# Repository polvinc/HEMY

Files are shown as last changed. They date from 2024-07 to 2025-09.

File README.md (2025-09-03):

# HEMY v2 – Harmonic Equatorial Mount Yourself

<!-- > _"When astronomy meets DIY and open source, accessible tools are born to explore the universe."_  
> — polvinc -->

**HEMY v2** is an open-source equatorial/alt-azimuth telescope mount designed for passionate astrophotographers and visual observers. Built around **harmonic drive technology**, HEMY offers high precision, portability, and affordability — without compromising on performance.

It is the result of a collaborative and iterative development effort to deliver a powerful, open-source alternative to proprietary commercial mounts.

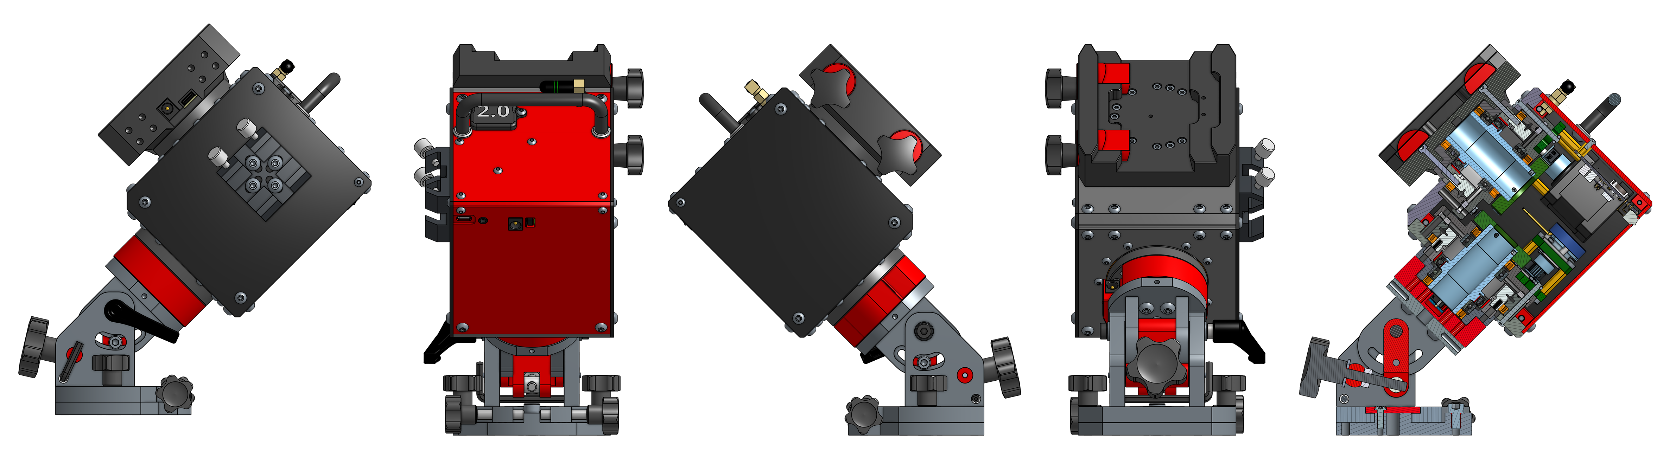
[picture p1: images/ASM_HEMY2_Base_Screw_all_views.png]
HEMY2_all_views


---

## 🚀 Project Description

**HEMY (Harmonic Equatorial Mount Yourself)** is a DIY telescope mount based on industrial-grade **harmonic reducers**, typically used in robotics. These reducers enable compact, backlash-free motion with high torque — ideal for precise astronomical tracking.

The project was created to address key issues in amateur astronomy equipment:
- High prices of commercial mounts
- Lack of openness and flexibility
- Complexity or incompatibility with personal setups

HEMY is:
- 🧰 **Cost-effective** – Total build cost under **800–1000 €**, with machined parts available for less than 400 €
- 🪶 **Portable & lightweight** – Less than 4 kg without base
- 🏗️ **Easy to build** – Designed for makers with basic tools
- 💪 **High-performance** – Accurate tracking (sub-arcsecond RMS), no counterweights needed

⚠️ **Important note about current status** ⚠️

This project is under continuous development. Initial performance tests are promising (13 kg and guiding <1 arcsec) and updates will be published regularly.

---

## ✨ Key Features

| Feature | Description |
|---|---|
| Mount Type | Equatorial / Alt-Az |
| Technology | Harmonic drive + timing belts + NEMA17 motors |
| Payload Capacity | Up to **15 kg**, no counterweights |
| Resolution | ~0.14 arcsec |
| Periodic Error | ~440s cycle, ~±10 arcsec peak-to-peak |
| Controller Compatibility | OnStepX, TeenAstro |
| Connectivity | USB-C, Wi-Fi, Bluetooth, integrated GPS |
| Features | RA axis brake, FRAM-based sensorless homing, 12V passthrough |
| Estimated Cost | ~800–1000 € total |
| Weight | < 4 kg (excluding base) |
| License | **GPL-3.0** |

---

## 🔧 Build Resources

- 🖥️ Full CAD files and STEP for mechanical parts  
- 🔗 [Link to _onshape_ project](https://cad.onshape.com/documents/5bb7abe94ccc1dfccd880b05/w/c4dcfbc560d188dfaca97350/e/5198383ed1b9d7f502f35102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)
- 🛠️ CNC-ready aluminum part kits (not available for now)  
- 📖 Detailed build guide and wiring instructions  
- 🧪 Currently tested and improved through real-world imaging

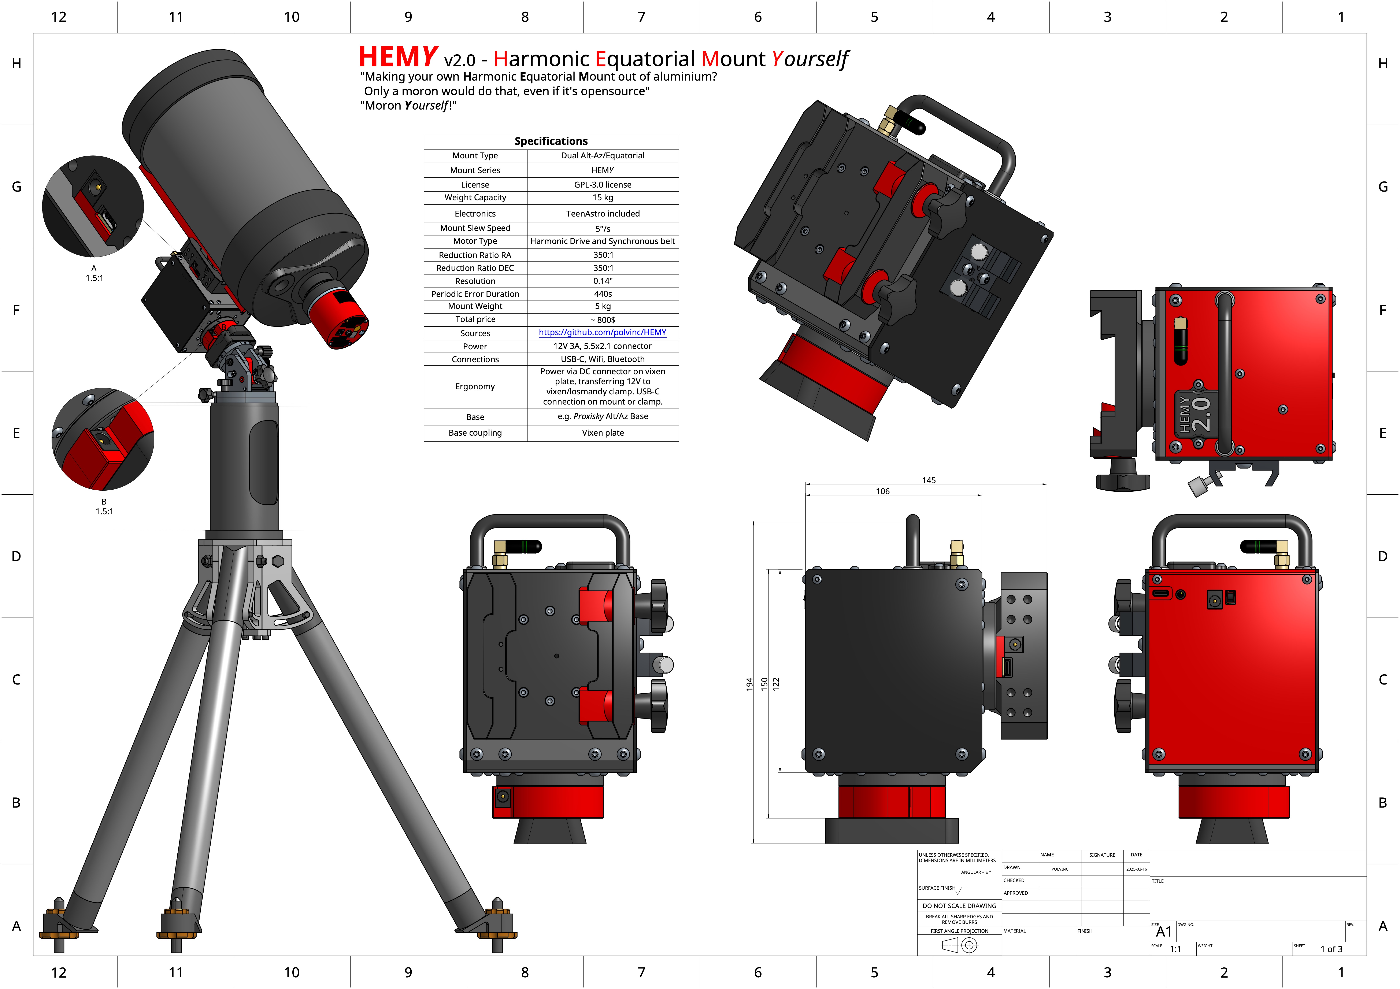
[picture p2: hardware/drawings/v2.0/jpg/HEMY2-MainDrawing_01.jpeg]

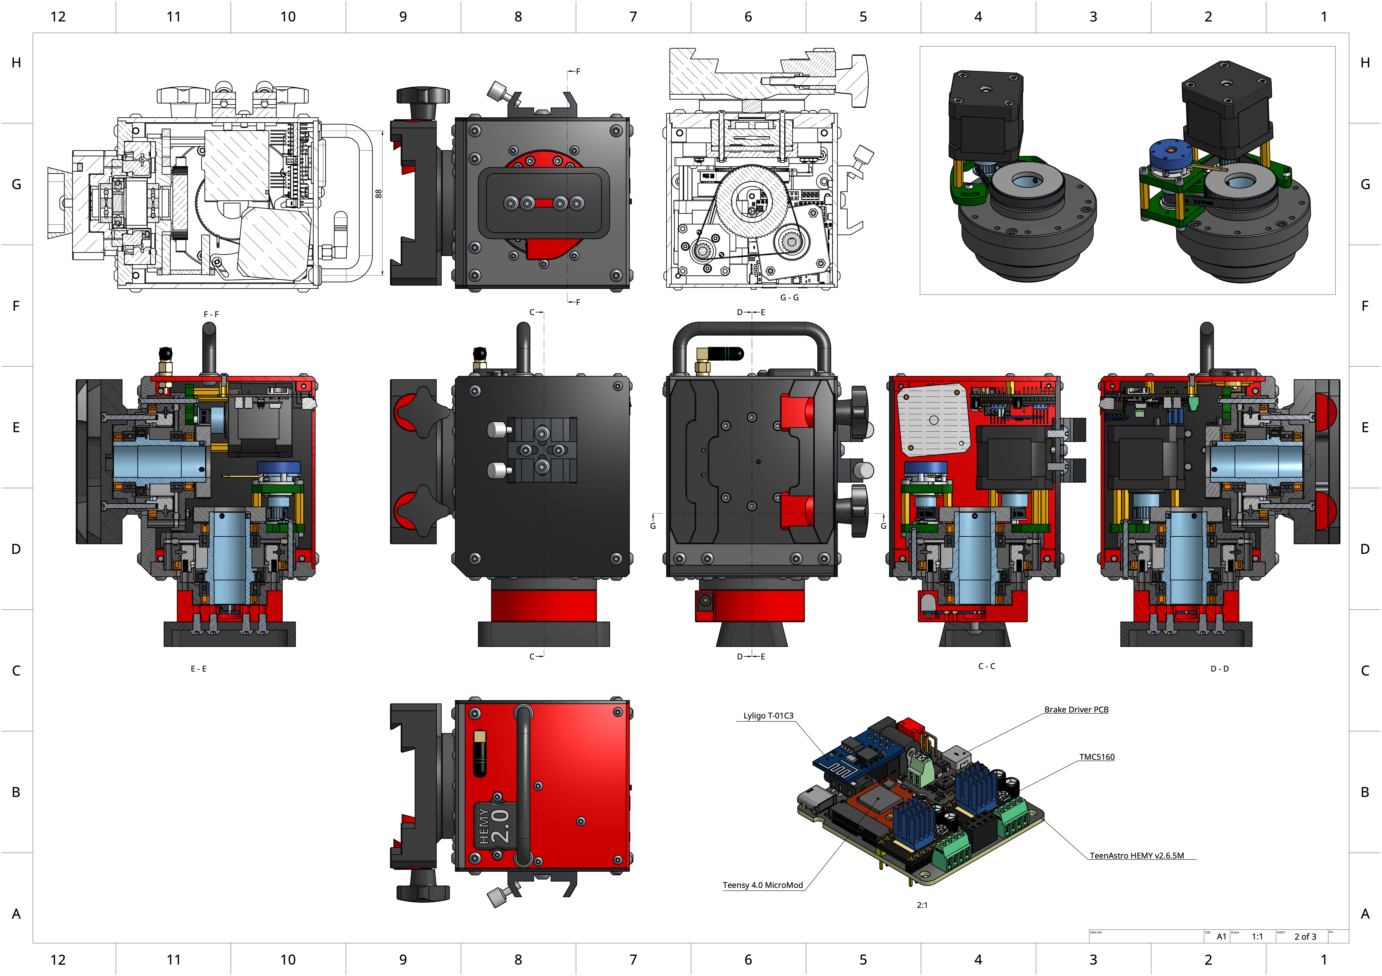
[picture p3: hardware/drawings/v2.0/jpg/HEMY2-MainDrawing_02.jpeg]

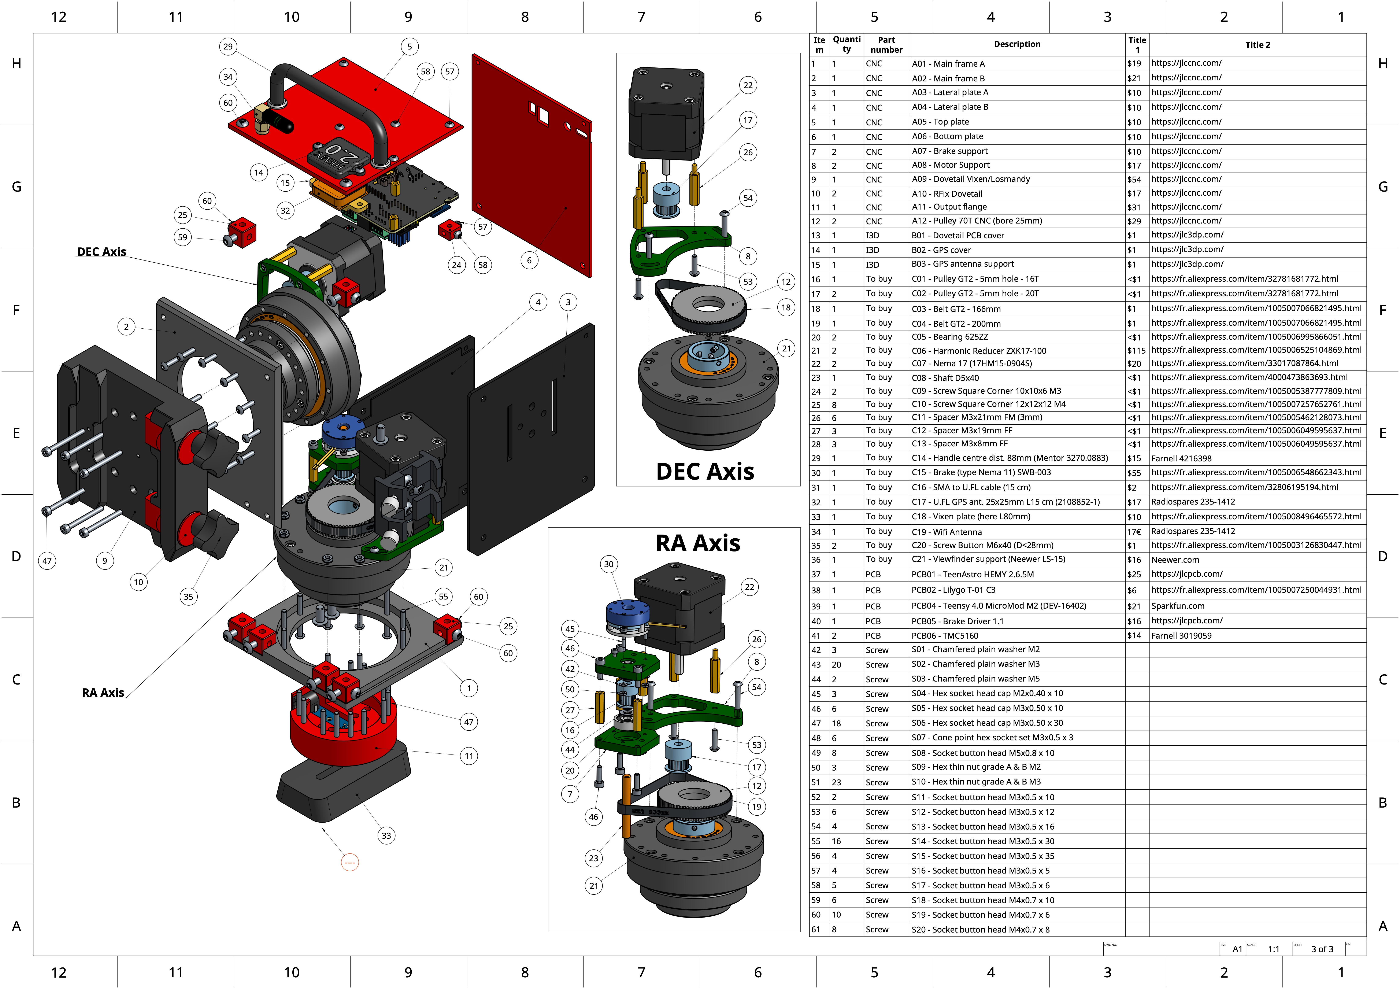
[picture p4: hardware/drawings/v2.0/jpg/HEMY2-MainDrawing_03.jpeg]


---

### Join the HEMY community on Discord ✨

We’ve opened a **Discord server** to bring together users, builders, and contributors around the open-source harmonic mount.

👉 [https://discord.gg/SYYkTSaXZt](https://discord.gg/SYYkTSaXZt)

Share ideas, get help, and follow the project’s progress with fellow astronomy enthusiasts.

---

## 🧩 Related Projects

### [AstrAlim – Astro Controller & Power Hub](https://github.com/dgedgedge/AstraDIY)

Developed as a companion project to HEMY, **AstrAlim** is a fully open-source power and control hub for astrophotography sessions, built around a Raspberry Pi and custom HATs.

**Key Features**:
- Smart power distribution and current monitoring
- Built-in dew heater control (PWM outputs)
- GPS synchronization (PPS), USB/serial passthrough
- Open INDI compatibility, ready for automation scripts
- All for under ~200 €, as a DIY build

Together, **HEMY + AstrAlim** provide a complete open-source ecosystem for serious astrophotography, without breaking the bank — and with full user control at every step.

---

## 📜 License

This project is licensed under the **GNU General Public License v3.0 (GPL-3.0)**.  
Feel free to use, modify, improve, and share — just keep it open.

---

## 🙌 Credits and support

Made with curiosity, solder fumes, and a deep love for the stars.  
By [@polvinc](https://github.com/polvinc). Inspirations from the open-source astro community.

### Why Support?
The development of HEMY V2 represents thousands of hours of work, research, and development. The journey involved:
- Multiple prototypes and iterations
- Extensive testing and validation
- Many failed attempts that led to improvements
- Significant personal investment in components and materials
- Countless nights of testing under the stars

While HEMY is open-source and free to use, the development process has been costly. Each iteration required new parts, and the path to the current successful design involved many expensive learning experiences.

Help me out for a couple of :beers: !

<a href="https://www.buymeacoffee.com/polvinc" target="_blank">Buy Me A Coffee</a>

---

## 🤝 Contributing

**Contributions are more than welcome!** Whether you're improving the documentation, proposing hardware tweaks, sharing your build, or contributing code – your help is greatly appreciated.

You can:
- Submit pull requests (PRs) for bug fixes, improvements, or new ideas
- Report issues or suggestions via GitHub Issues
- Participate in ongoing discussions

👉 A dedicated **[Discussions](https://github.com/polvinc/HEMY/discussions)** section is open for:
- Build logs and photos 📸  
- Tips and tricks 🔧  
- Questions, troubleshooting, and ideas 💬  
- Forks and derivatives 🚀

Let’s build a community of tinkerers, dreamers, and stargazers. Your input helps make HEMY better for everyone!

### Other Ways to Contribute
- Star the project on GitHub
- Share your build experiences and results
- Report bugs and suggest improvements
- Help improve documentation
- Share the project with other astronomy enthusiasts

Your support, whether financial or through contribution to the project, is greatly appreciated and helps keep this project alive and growing! 🚀✨

---

## Bill of Materials (BOM)

See [BOM.md](docs/v2/BOM.md).

### Total Estimated Cost: ~$800 without base

There are two possibilities for the alt/az base of the mount: either the HEMY v1 base, or the poxisky base which is very well sized for the project and less expensive.

Note: Prices are approximate and may vary depending on supplier and location.

---

## 🔌 Electronics Overview

The electronics system of **HEMY v2** is fully custom-designed and built around a compact stack of modular PCBs. It includes:

- A main control board based on the **Teensy 4.0 MicroMod** running [OnStepX](https://github.com/hjd1964/OnStepX)
- Two **TMC5160 stepper drivers** for precise, silent microstepping
- An optional **brake driver** for locking the RA axis when idle
- A **LilyGO T-01 C3** Wi-Fi module for remote control via web or INDI
- Integrated **GPS** with PPS, power passthrough, and USB routing

All boards were designed using open-source tools and are published on [OSHWHub – HEMY 2.0 project](https://oshwlab.com/pololamag/hemy-2-0), where you can view the schematics, order PCBs, or remix them to fit your needs.

> 🧠 The electronics stack is plug-and-play compatible with the mechanical mount and was developed specifically to minimize wiring, improve modularity, and enable clean integration into astrophotography workflows.

---

## 🛠️ Assembly Guide

See [Assembly.md](docs/v2/Assembly.md).

The image below shows the complete set of mechanical and electronic parts required to build **HEMY v2**.

Each component has been carefully selected or designed to ensure high mechanical precision and ease of assembly. From CNC-machined aluminum plates and harmonic reducers to the stepper motors and controller board — this kit represents the full DNA of HEMY.

> Use this photo as a reference before you begin — for inventory, orientation, and inspiration.

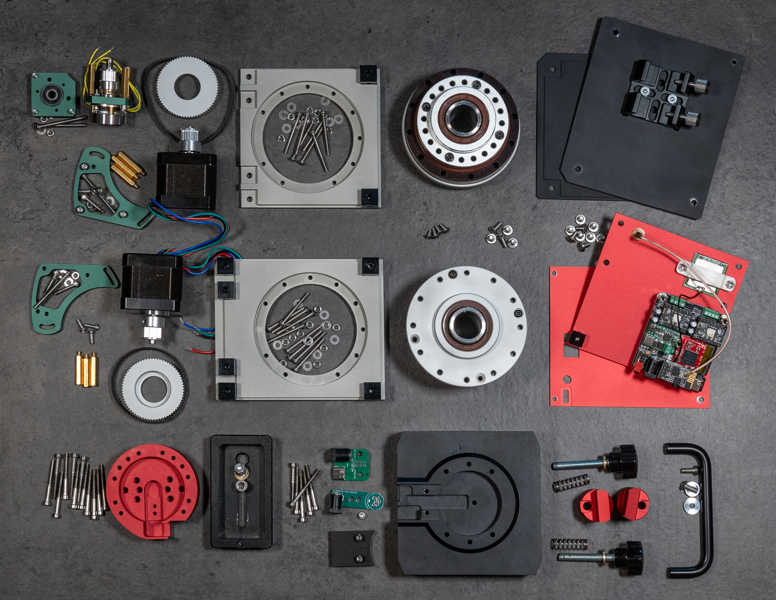
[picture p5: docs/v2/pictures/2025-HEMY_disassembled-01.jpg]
HEMY v2 – Parts Overview


---

### ✅ Pre-Assembly Checklist

Before getting started, make sure you have:

#### Tools
- [ ] Metric Allen (hex) key set  
- [ ] Phillips and flathead screwdrivers  
- [ ] Pliers and precision tweezers  
- [ ] Threadlocker (Loctite) — optional but recommended  
- [ ] Caliper or ruler  
- [ ] Soldering iron (if modifying electronics)

#### Workspace
- [ ] Clean, flat, well-lit surface  
- [ ] Small trays for sorting screws and components  
- [ ] Antistatic precautions for electronics  

#### Documentation
- [ ] This README and [detailed assembly docs](/docs/v2/Assembly.md)  
- [ ] Exploded views and diagrams (see `hardware/drawings` folder)

---

<!-- 
### 🧱 Assembly Overview

Here’s the high-level assembly plan:

1. **🧩 Frame Assembly**  
   - Mount structural plates and base components  
   - Insert harmonic drives into RA and DEC sections  

2. **🔩 Motor Installation**  
   - Attach NEMA17 motors and pulleys  
   - Fit belts and adjust tension  

3. **⚙️ Axis Construction**  
   - Assemble RA and DEC units  
   - Install bearings, brake, and homing components  

4. **🔌 Electronics Setup**  
   - Mount controller (OnStepX or TeenAstro)  
   - Wire motors, GPS, and power distribution  
   - Connect USB, Wi-Fi, Bluetooth, and dew heater if applicable  

5. **🔭 Final Touches**  
   - Install dovetail clamp and polar finder bracket  
   - Route cables cleanly  
   - Power up, configure firmware, and start tracking! -->

See [Assembly.md](docs/v2/Assembly.md).

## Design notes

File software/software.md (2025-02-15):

# Software/Firmware Configuration
## Introduction
HEM*Y* uses the [OnStepX](https://github.com/hjd1964/OnStepX) ([wiki](https://groups.io/g/onstep/wiki/home)) computerized telescope control firmware, a free and open-source project released under the GPL version 3.  You'll need to compile and flash this firmware to your main board following the instructions below.  These instructions are adapted from the [wiki](https://onstep.groups.io/g/main/wiki/32777), where you can find more detail if desired.

## Install the Arduino IDE
You'll compile the firmware using the latest version of the Arduino IDE, which is available for Windows, macOS, and Linux.  Download it from https://www.arduino.cc/en/software and install it, if it isn't already installed.

## Install Teensy Support
The TeenAstro Redux board uses a Teensy 4.0 on a MicroMod card, so you'll need to install Teensy support in the Arduino IDE.  To do this, in the Arduino IDE, go to File -> Preferences (Arduino IDE -> Settings under macOS), and enter `https://www.pjrc.com/teensy/package_teensy_index.json` in the **Additional Boards Manager URLs** field.  If that field isn't empty, separate any URLs with commas, like this: `https://www.pjrc.com/teensy/package_teensy_index.json,https://raw.githubusercontent.com/espressif/arduino-esp32/gh-pages/package_esp32_index.json`.  Then click OK.  Then go to Tools -> Board -> Boards Manager and install Teensy support.

## Install Support Libraries
You'll next need to install libraries to support some of the devices you'll be using.  Go to Tools -> Manage Libraries and install the following libraries:
* Makuna RTC, version 2.3.5
* Time, version 1.6.1
* TinyGPSPlusPlus, latest version
+ TMCStepper

## Download the OnStepX Code
Browse to https://github.com/hjd1964/OnStepX to download the OnStepX code.  As of this writing (15 Feb 25), the latest release published is 10.24c, and you must use at least version 10.24i.  If there's a release more recent than 10.24i on the Releases page, you can download and use that.  Otherwise, click the green **Code** button to download a `.zip` file of the repository.  Unzip, and rename its folder to `OnStepX` (it will likely default to `OnStepX-main`).

Also, download the [Config.h](Config.h) file from this repository.  Place it in the `OnStepX` folder, overwriting the copy that's already there.

## Flash the Firmware
You'll need to prepare your hardware.  Install the Teensy MicroMod onto the main board and secure it in place with an M3x6 screw.  Connect the board to 12-24V DC power.  Plug in a USB cable from your computer to the board.  Turn on the power switch on the board.  The white LED on the board should turn on, and after a moment, the blue LED on the Teensy should also turn on.  The Arduino IDE should recognize that a `Teensy MicroMod` is connected.

To compile and flash the firmware, either click the Upload button in the code window (the arrow in the upper-left corner), or go to Sketch -> Upload.  Compilation and uploading will take a few moments, after which the Teensy will reset.

## Test
Connect to your controller using the Serial Monitor in the Arduino IDE, and type the following command: `:GVP#`, then press Enter.  It should respond with `On-Step#`.

## ESP-01S
Unknown what, if anything, needs to be done with respect to the WiFi device.

## Hand Controller
TODO

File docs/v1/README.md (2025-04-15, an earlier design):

# Ongoing repo
The repository is still under construction, as I still haven't been able to test the HEMY mount as much as I'd like. Prior to the v1.1 upgrade, which corrected certain aspects of its performance, I was able to guide an equipped scope (total 13kg) with less than 1 arcsec in guiding. The v1.1 upgrade should improve guiding performance.

# V2 is almost ready
See [drawing](drawings/v2.0/HEMY2-MainDrawing.pdf).
See [electronics](https://oshwlab.com/pololamag/hemy-2-0).

## Support

Hey! Help me out for a couple of :beers: !

<a href="https://www.buymeacoffee.com/polvinc" target="_blank">Buy Me A Coffee</a>

# HEM*Y*: Harmonic Equatorial Mount *Yourself*
## What the hell is this HEM*Y* thing?

HEMY (Harmonic Equatorial Mount *Yourself*) is an open-source harmonic equatorial mount for observation or astrophotography. It is based on the use of a harmonic reducer. The mount is designed to be inexpensive in relation to its performance, transportable, with a relatively large load capacity. Most importantly, this mount is easy to build: no need for machine tools or other laser-cutting-water-jet-plasma-turbo-piston-5-axis machines, you can order the CNC aluminium parts for less than 300€. A shopping list, a screwdriver, a saw and some resourcefulness: you've got everything you need to make an HEM*Y*. The ultimate aim is to distribute its design as an open-source product for personal use.

The technology used in this mount is similar to that used in robotics or industrial production lines. The main mechanical gearbox is a harmonic gearbox ([wikipedia](https://en.wikipedia.org/wiki/Strain_wave_gearing)). 



It can produce surprising results for an astronomical mount at first glance; the mount appears grossly undersized and unbalanced, whereas the whole assembly is extremely robust and stable, with enormous torque.
Conventional equatorial mounts require the use of counterweights. The aim of this development is to make available the design of a harmonic mount that can be built in your garage, with few tools or mechanical knowledge, for a price of less than 800€. Of course, the proud aim is to achieve performance equivalent to that of commercial harmonic reduction mounts.

The first results of the performance tests are up to my expectations for the moment. I hope this github repository can help you design or reproduce this equatorial mount. Please be patient, I'm only working on this project in my spare time. I'll update the testing progress on this readme. ✍️

## Support

Hey! Help me out for a couple of :beers: !

<a href="https://www.buymeacoffee.com/polvinc" target="_blank">Buy Me A Coffee</a>

## What are the specifications

TODO

# Assembly

TODO

## HEM*Y* Mount drawings

/!\ The pulleys are 16T and 60T for DEC. The reduction ratio is 3.75:1 instead of 3:1...

TODO

<p align="center">
  <a href="drawings/v1.1/pdf/Drawing_HEMY_Mount.pdf" target="_blank">
    
  </a>
  <a href="drawings/v1.1/pdf/Drawing_HEMY_Mount.pdf" target="_blank">
    
  </a>
</p> <p align="center">
  <a href="drawings/v1.1/pdf/Drawing_HEMY_Mount.pdf" target="_blank">
    
  </a>
  <a href="drawings/v1.1/pdf/Drawing_HEMY_Mount.pdf" target="_blank">
    
  </a>
</p> <p align="center">
  <a href="drawings/v1.1/pdf/Drawing_HEMY_Mount.pdf" target="_blank">
    
  </a>
  <a href="drawings/v1.1/pdf/Drawing_HEMY_Mount.pdf" target="_blank">
    
  </a>
</p> <p align="center">
  <a href="drawings/v1.1/pdf/Drawing_HEMY_Mount.pdf" target="_blank">
    
  </a>
  <a href="drawings/v1.1/pdf/Drawing_HEMY_Mount.pdf" target="_blank">
    
  </a>
</p> <p align="center">
  <a href="drawings/v1.1/pdf/Drawing_HEMY_Mount.pdf" target="_blank">
    
  </a>
  <a href="drawings/v1.1/pdf/Drawing_HEMY_Mount.pdf" target="_blank">
    
  </a>
</p> <p align="center">
  <a href="drawings/v1.1/pdf/Drawing_HEMY_Mount.pdf" target="_blank">
    
  </a>
</p>

## HEM*Y* Base drawings
TODO

<p align="center">
  <a href="drawings/v1.1/pdf/Drawing_HEMY_Base.pdf" target="_blank">
    
  </a>
  <a href="drawings/v1.1/pdf/Drawing_HEMY_Base.pdf" target="_blank">
    
  </a>
</p> <p align="center">
  <a href="drawings/v1.1/pdf/Drawing_HEMY_Base.pdf" target="_blank">
    
  </a>
  <a href="drawings/v1.1/pdf/Drawing_HEMY_Base.pdf" target="_blank">
    
  </a>
</p> <p align="center">
  <a href="drawings/v1.1/pdf/Drawing_HEMY_Base.pdf" target="_blank">
    
  </a>
</p>

## HEM*Y* Parts catalog drawings
TODO
<p align="center">
  <a href="drawings/v1.1/pdf/Drawing_HEMY_Parts.pdf" target="_blank">
    
  </a>
  <a href="drawings/v1.1/pdf/Drawing_HEMY_Parts.pdf" target="_blank">
    
  </a>
  <a href="drawings/v1.1/pdf/Drawing_HEMY_Parts.pdf" target="_blank">
    
  </a>
  <a href="drawings/v1.1/pdf/Drawing_HEMY_Parts.pdf" target="_blank">
    
  </a>
</p> <p align="center">
  <a href="drawings/v1.1/pdf/Drawing_HEMY_Parts.pdf" target="_blank">
    
  </a>
  <a href="drawings/v1.1/pdf/Drawing_HEMY_Parts.pdf" target="_blank">
    
  </a>
  <a href="drawings/v1.1/pdf/Drawing_HEMY_Parts.pdf" target="_blank">
    
  </a>
  <a href="drawings/v1.1/pdf/Drawing_HEMY_Parts.pdf" target="_blank">
    
  </a>
</p> <p align="center">
  <a href="drawings/v1.1/pdf/Drawing_HEMY_Parts.pdf" target="_blank">
    
  </a>
  <a href="drawings/v1.1/pdf/Drawing_HEMY_Parts.pdf" target="_blank">
    
  </a>
  <a href="drawings/v1.1/pdf/Drawing_HEMY_Parts.pdf" target="_blank">
    
  </a>
  <a href="drawings/v1.1/pdf/Drawing_HEMY_Parts.pdf" target="_blank">
    
  </a>
</p> <p align="center">
  <a href="drawings/v1.1/pdf/Drawing_HEMY_Parts.pdf" target="_blank">
    
  </a>
  <a href="drawings/v1.1/pdf/Drawing_HEMY_Parts.pdf" target="_blank">
    
  </a>
  <a href="drawings/v1.1/pdf/Drawing_HEMY_Parts.pdf" target="_blank">
    
  </a>
  <a href="drawings/v1.1/pdf/Drawing_HEMY_Parts.pdf" target="_blank">
    
  </a>
</p> <p align="center">
  <a href="drawings/v1.1/pdf/Drawing_HEMY_Parts.pdf" target="_blank">
    
  </a>
  <a href="drawings/v1.1/pdf/Drawing_HEMY_Parts.pdf" target="_blank">
    
  </a>
  <a href="drawings/v1.1/pdf/Drawing_HEMY_Parts.pdf" target="_blank">
    
  </a>
  <a href="drawings/v1.1/pdf/Drawing_HEMY_Parts.pdf" target="_blank">
    
  </a>
</p>

## BOM

See [BOM.md](BOM.md).

## Software configuration

See [software.md](software/software.md)

## Harmonic drive
Harmonic gearboxes ([wikipedia](https://en.wikipedia.org/wiki/Strain_wave_gearing)), or more precisely strain wave gears, are a type of gear mechanism that transmits much more torque than other common gears. This is mainly due to the fact that there are many more teeth engaged at once. One of the major advantages of these gears is that they have virtually no backlash, partly because they use deformation. It's a bit like belts, which are supposed to be more or less backlash-free, but harmonic gearboxes use deformable metal spring steels, which are much better than belts.

Put another way, in the case of an astronomical mount: they can drive much heavier loads without the need for counterweights, all with a very low self-weight!

The harmonic reducer model chosen [CSF-17-100-2UH](https://harmonicdrive.de/fileadmin/user_upload/Harmonic_Drive_Gears_EN_1050860_06_2022.pdf#page=50) is the same as [Alan](https://alanz.info/posts/2022/07/diy-mount/) DIY mount. You can find lots of them on ebay. This one has a reduction ratio of 1/100. It has the good fortune to meet my requirements, and to have been tested for another equatorial mount. Why deprive yourself? According to datasheet, it can handle more than 50Nm of torque and it also has a very comfortable permissible radial load of over 70Kg.
On AliExpress, you can find [HBS-17](https://fr.aliexpress.com/item/1005007101363756.html?gatewayAdapt=glo2fra), much cheaper (used for HEMY).

TODO TeenAstro Redux Electronics / OnstepX

Using [OnStep's configurator spreadsheet](http://o.baheyeldin.com:1111), I chose to drive the harmonic gearbox with a belt/pulley couple, in order to achieve good tracking resolution, a good slew rate and a good number of steps/deg.

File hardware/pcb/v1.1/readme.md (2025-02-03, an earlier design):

See [Oshwlab](https://oshwlab.com/lordzurp/teenastro-redux)

There's still an error in the footprint of the M.2 connector. Don't forget to correct the footprint and follow the manufacturer's recommendations for the two positioning holes.

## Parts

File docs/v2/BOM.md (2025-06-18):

# 📦 Bill of Materials (BOM) – HEMY v2

This is the full Bill of Materials required to build the HEMY v2 harmonic equatorial mount. Parts are categorized by how they are sourced or manufactured: CNC-machined aluminum, 3D-printed parts, purchased components, electronics, and hardware.

---

## 🛠️ CNC Machined Parts (Aluminum)
Manufactured via CNC – recommended supplier: [jlccnc.com](https://jlccnc.com/)

Step to upload are there : [../../hardware/step/v2.0/](../../hardware/step/v2.0/)

The complete file set is here : [ASM_HEMY2.step.zip](../../../hardware/step/v2.0/ASM_HEMY2.step.zip)

| # | Qty | Ref | Description | Est. Price | step file |
|---|-----|---|---|---|---|
| 1 | 1 | A01 | Main frame A | $19 | [HEMY2 - Main frame A.step](../../../hardware/step/v2.0/HEMY2%20-%20Main%20frame%20A.step) |
| 2 | 1 | A02 | Main frame B | $21 | [HEMY2 - Main frame B.step](../../../hardware/step/v2.0/HEMY2%20-%20Main%20frame%20B.step) |
| 3 | 1 | A03 | Lateral plate A | $10 | [HEMY2 - Lateral A.step](../../../hardware/step/v2.0/HEMY2%20-%20Lateral%20A.step) |
| 4 | 1 | A04 | Lateral plate B | $10 | [HEMY2 - Lateral B.step](../../../hardware/step/v2.0/HEMY2%20-%20Lateral%20B.step) |
| 5 | 1 | A05 | Top plate | $10 | [HEMY2 - Top plate.step](../../../hardware/step/v2.0/HEMY2%20-%20Top%20plate.step) |
| 6 | 1 | A06 | Bottom plate | $10 | [HEMY2 - Bottom plate.step](../../../hardware/step/v2.0/HEMY2%20-%20Bottom%20plate.step) |
| 7 | 2 | A07 | Brake support | $10 | [HEMY2 - Brake support.step](../../../hardware/step/v2.0/HEMY2%20-%20Brake%20support.step) |
| 8 | 2 | A08 | Motor support | $17 | [HEMY2 - Motor Support.step](../../../hardware/step/v2.0/HEMY2%20-%20Motor%20Support.step) |
| 9 | 1 | A09 | Dovetail Vixen/Losmandy | $54 | [HEMY2 - Dovetail.step](../../../hardware/step/v2.0/HEMY2%20-%20Dovetail.step) |
|10 | 2 | A10 | RFix Dovetail | $17 | [HEMY2 - Dovetail Fix.step](../../../hardware/step/v2.0/HEMY2%20-%20Dovetail%20Fix.step) |
|11 | 1 | A11 | Output flange | $31 | [HEMY2 - Output DC base.step](../../../hardware/step/v2.0/HEMY2%20-%20Output%20DC%20base.step) |
|12 | 2 | A12 | Main pulley | $30 | [HEMY2 - Pulley 70Ts CNC.step](../../../hardware/step/v2.0/HEMY2%20-%20Pulley%2070Ts%20CNC.step) |
|13 | 1 | A13 | SWB-003-shaft coupling | $ | [HEMY2 - SWB-003-shaft coupling.step](../../../hardware/step/v2.0/HEMY2%20-%20SWB-003-shaft%20coupling.step) |

---

## 🧱 3D Printed Parts (Aesthetic Covers)
Printed via FDM or resin printer – non-functional (cosmetic only)

They can be ordered here : [https://jlc3dp.com/](https://jlc3dp.com/)

| # | Qty | Ref  | Description | Est. Price | Link |
|---|-----|---|---|---|---|
|13 | 1 | B01  | Dovetail PCB cover | $1 | [HEMY2 - I3D - Dovetail PCB cover.step](../../../hardware/step/v2.0/HEMY2%20-%20I3D%20-%20Dovetail%20PCB%20cover.step) |
|14 | 1 | B02  | GPS cover | $1 | [HEMY2 - I3D - GPS cover.step ](../../../hardware/step/v2.0/HEMY2%20-%20I3D%20-%20GPS%20cover.step)|
|15 | 1 | B03  | GPS antenna support | $1 | [HEMY2 - I3D - Antenna Support.step](../../../hardware/step/v2.0/HEMY2%20-%20I3D%20-%20Antenna%20Support.step) |

---

## 🛍️ Parts to Purchase (Mechanical & Electronics)

| # | Qty | Ref | Description | Est. Price | Link |
|---|-----|---|---|---|---|
|16 | 1 | C01 | GT2 Pulley 16T (5mm bore) - W6mm | <$1 | https://fr.aliexpress.com/item/32781681772.html |
|17 | 2 | C02 | GT2 Pulley 20T (5mm bore) - W6mm | <$1 | https://fr.aliexpress.com/item/32781681772.html |
|18 | 1 | C03 | GT2 Belt – 166 mm | $1 | https://fr.aliexpress.com/item/1005007066821495.html |
|19 | 1 | C04 | GT2 Belt – 200 mm | $1 | https://fr.aliexpress.com/item/1005007066821495.html |
|20 | 2 | C05 | Bearing 625ZZ | <$1 | https://fr.aliexpress.com/item/1005006995866051.html |
|21 | 2 | C06 | Harmonic Reducer ZXK17-100 | $115 | https://fr.aliexpress.com/item/1005006525104869.html |
|22 | 2 | C07 | Nema 17 (17HM15-0904S) | $20 | https://fr.aliexpress.com/item/33017087864.html |
|23 | 1 | C08 | Shaft 5x40mm-Grind Flat (see note below) | <$1 | https://fr.aliexpress.com/item/1005004016804299.html <!-- https://fr.aliexpress.com/item/1005004046126519.html | -->
|24 | 2 | C09 | Square Corner Screw 10x10x6 M3 | <$1 | https://fr.aliexpress.com/item/1005005387777809.html |
|25 | 8 | C10 | Square Corner Screw 12x12x12 M4 | <$1 | https://fr.aliexpress.com/item/1005007257652761.html |
|26 | 6 | C11 | Spacer M3x21mm FM  - (Thread 4mm) | <$1 | https://fr.aliexpress.com/item/1005005462128073.html |
|27 | 3 | C12 | Spacer M3x19mm FF | <$1 | https://fr.aliexpress.com/item/1005006049595637.html |
|28 | 3 | C13 | Spacer M3x8mm FF | <$1 | https://fr.aliexpress.com/item/1005006049595637.html |
|29 | 1 | C14 | Handle (Mentor 3270.0883) | $15 | Farnell 4216398 |
|30 | 1 | C15 | Nema 11 Brake (SWB-003) | $55 | https://fr.aliexpress.com/item/1005006548662343.html |
|31 | 1 | C16 | SMA to U.FL cable (15 cm) | $2 | https://fr.aliexpress.com/item/32806195194.html |
|32 | 1 | C17 | U.FL GPS Antenna 25x25mm | $17 | Radiospares 235-1412 |
|33 | 1 | C18 | Vixen plate (L80mm) | $10 | https://fr.aliexpress.com/item/1005008496465572.html |
|34 | 1 | C19 | Wi-Fi Antenna | $17 | Radiospares 124-8672 |
|35 | 2 | C20 | Screw Button M6x40 (D<28mm) | $1 | https://fr.aliexpress.com/item/1005003126830447.html |
|36 | 1 | C21 | Viewfinder support | $16 | https://fr.aliexpress.com/item/1005005998174975.html |
|36 | 1 | C21 | Spring 8mm OD, 0.8mm Wire, 25mm Free Length  | $1 | https://fr.aliexpress.com/item/1005001408406253.html |

> ⚠️ **Important Note:** The original SWB-003 shaft coupling is not compatible with any shaft we found, particularly this one. Therefore, I designed the CNC part A13 (could be printed, not tested) to replace the original shaft coupling. Another solution is to grind the shaft to increase the flat surface. In fact, the original coupler has a flat spot 4mm away from the opposite edge, whereas the flattened shaft from AliExpress has its flat spot 4.5mm away. In this case it is necessary to grind to 0.5mm.

---

## 🔌 PCBs & Electronics

| # | Qty | Ref | Description | Est. Price | Link |
|---|-----|---|---|---|---|
|37 | 1 | PCB01 | TeenAstro HEMY 2.6.5M PCB | $25 | https://jlcpcb.com/ |
|38 | 1 | PCB02 | Lilygo T-01 C3 | $6 | https://fr.aliexpress.com/item/1005007250044931.html |
|39 | 1 | PCB04 | Teensy 4.0 MicroMod M2 | $21 | Sparkfun.com |
|40 | 1 | PCB05 | Brake Driver 1.1 | $16 | https://jlcpcb.com/ |
|41 | 2 | PCB06 | TMC5160 Stepper Drivers | $14 | Farnell 3019059 |

---

## 🔩 Fasteners & Hardware

> ⚠️ **Important Note:** The fastener list below has not been fully optimized. Rationalization efforts (standardizing screw types and lengths) are very welcome. SHCS are generally preferred over BHCS for durability.

| # | Qty | Ref | Description |
|----|-----|---|---|
|42  | 3 | S01 | Chamfered plain washer M2 |
|43  | 20  | S02 | Chamfered plain washer M3 |
|44  | 2 | S03 | Chamfered plain washer M5 |
|45  | 3 | S04 | Hex socket head cap M2x10 |
|46  | 6 | S05 | Hex socket head cap M3x10 |
|47  | 23  | S06 | Hex socket head cap M3x30 |
|48  | 6 | S07 | Cone point hex socket set M3x3 |
|49  | 8 | S08 | Socket button head M5x10 |
|50  | 3 | S09 | Hex thin nut M2 |
|51  | 23  | S10 | Hex thin nut M3 |
|52  | 2 | S11 | Socket button head M3x10 |
|53  | 6 | S12 | Socket button head M3x12 |
|54  | 4 | S13 | Socket button head M3x16 |
|55  | 16  | S14 | Socket button head M3x30 |
|56  | 4 | S15 | Socket button head M3x35 |
|57  | 4 | S16 | Socket button head M3x5 |
|58  | 5 | S17 | Socket button head M3x6 |
|59  | 6 | S18 | Socket button head M4x10 |
|60  | 10  | S19 | Socket button head M4x6 |
|61  | 8 | S20 | Socket button head M4x8 |

For metric threads like M2, M3, etc., the pitch is standardized. The International Organization for Standardization (ISO) defines the standards for metric screw threads, which include specifications for thread pitch.

* Note 1 : Here are the metric thread sizes and their standard coarse pitches you shall comply with :
   * M2: Typically has a pitch of 0.4 mm.
   * M2.5: Typically has a pitch of 0.45 mm.
   * M3: Typically has a pitch of 0.5 mm.
   * M4: Typically has a pitch of 0.7 mm.
   * M5: Typically has a pitch of 0.8 mm.
   * M6: Typically has a pitch of 1.0 mm.
   * M8: Typically has a pitch of 1.25 mm.
   * M10: Typically has a pitch of 1.5 mm.
* Note 2 :
   The dimensions of a "Chamfered plain washer M2" are generally standardized to ensure compatibility with M2 screws and bolts. Standardization helps ensure that washers from different manufacturers can be used interchangeably. Here are the typical dimensions for an M2 chamfered plain washer:
  
   * Inner Diameter (ID): Approximately 2.2 mm to fit an M2 screw.
   * Outer Diameter (OD): Typically around 5 mm, though this can vary slightly depending on the specific standard or manufacturer.
   * Thickness: Usually around 0.5 mm, but this can also vary slightly.

## Tooling set

To be able to do the assembly you will need some tools which are listed here.
The list may not be complete.

| #  | Ref | Description |
|----|-----|---|
|42  | T01 | Allen key ball-end hex keys  Size 1.5 mm  |

---

## 🧐 Contributions Welcome
Found a better part? Optimized the screw selection? Help make this BOM easier to use and more accessible to everyone — feel free to open a PR!

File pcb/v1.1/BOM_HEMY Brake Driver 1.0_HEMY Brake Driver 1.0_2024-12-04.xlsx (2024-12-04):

No. | Quantity | Comment | Designator | Footprint | Value | Manufacturer Part | Manufacturer | Supplier Part | Supplier | LCSC Part Name
1 | 2 | 22uF | C1,C3 | C0805 | 22uF | CGA0805X5R226M350MT | HRE(芯声) | C6119901 | LCSC | 22uF ±20% 35V
2 | 1 | 100nF | C2 | C0805 | 100nF | CC0805KRX7R9BB104 | YAGEO(国巨) | C49678 | LCSC | 100nF ±10% 50V
3 | 1 | 100nF | C4 | C0603 | 100nF | CC0603KRX7R9BB104 | YAGEO(国巨) | C14663 | LCSC | 100nF±10%50V
4 | 1 | 100pF | C5 | C0603 | 100pF | CL10C101JB8NNNC | SAMSUNG(三星) | C14858 | LCSC | 100pF ±5% 50V
5 | 1 | SS34 | D1 | SMA_L4.3-W2.6-LS5.2-RD |  | SS34 | MDD(辰达半导体) | C8678 | LCSC | 电压:40V 电流:3A
6 | 1 | ES3DB | D2 | SMB_L4.6-W3.6-LS5.3-RD |  | ES3DB | MDD(辰达半导体) | C64975 | LCSC | 电压:200V 电流:3A
7 | 1 | Test-Point | FAULT | Test-Point-0.5mm
8 | 1 | 22uH | L1 | IND-SMD_L7.1-W6.6 | 22uH | YSPI0630A-220M | YJYCOIN(益嘉源) | C497873 | LCSC | 22uH ±20%
9 | 1 | 6210XX21821_62100421821_ | P1 | 62100421821
10 | 1 | MX128-2.54-02P | P3 | CONN-TH_2P-P2.54_MX128-2.54-GN01-02P-CU-Y-A |  | MX128-2.54-02P | MAX(迈旭) | C5188442 | LCSC | 2.54mm 1x2P 排数:1 每排P数:2 直插
11 | 1 | MMBT3904 | Q1 | SOT-23-3_L2.9-W1.3-P1.90-LS2.4-BR |  | MMBT3904 | CJ(江苏长电/长晶) | C20526 | LCSC | NPN 电流:200mA 耐压:40V hfe=100~300
12 | 1 | 82kΩ | R1 | R0603 | 82kΩ | 0603WAF8202T5E | UNI-ROYAL(厚声) | C23254 | LCSC | 82kΩ ±1% 100mW 厚膜电阻
13 | 1 | 2.2kΩ | R2 | R0603 | 2.2kΩ | 0603WAF2201T5E | UNI-ROYAL(厚声) | C4190 | LCSC | 2.2kΩ ±1% 100mW 厚膜电阻
14 | 1 | 33kΩ | R3 | R0603 | 33kΩ | 0603WAF3302T5E | UNI-ROYAL(厚声) | C4216 | LCSC | 33kΩ ±1% 100mW 厚膜电阻
15 | 1 | 47kΩ | R4 | R0603 | 47kΩ | 0603WAF4702T5E | UNI-ROYAL(厚声) | C25819 | LCSC | 47kΩ ±1% 100mW 厚膜电阻
16 | 2 | 4.7kΩ | R7,R8 | R0603 | 4.7kΩ | 0603WAF4701T5E | UNI-ROYAL(厚声) | C23162 | LCSC | 4.7kΩ ±1% 100mW 厚膜电阻
17 | 1 | SDB628 | U1 | SOT-23-6_L2.9-W1.6-P0.95-LS2.8-BR |  | SDB628 | SHOUDING(首鼎半导体) | C77805 | LCSC | SDB628
18 | 1 | DRV103H/2K5 | U2 | SOIC-8_L4.9-W3.9-P1.27-LS6.0-BL-EP2.3 |  | DRV103H/2K5 | TI(德州仪器) | C544418 | LCSC | DRV103H/2K5

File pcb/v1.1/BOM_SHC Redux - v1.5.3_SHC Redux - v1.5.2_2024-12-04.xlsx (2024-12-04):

No. | Quantity | Comment | Designator | Footprint | Value | Manufacturer Part | Manufacturer | Supplier Part | Supplier | LCSC Part Name
1 | 5 | 100nF | C1,C2,C3,C4,C5 | C_0603 |  | CC0603KRX7R9BB104 | YAGEO | C14663 | LCSC
2 | 1 | 100uF | C8 | CAP-SMD_L3.5-W2.8 |  | TAJB107K006RNJ | AVX | C16133 | LCSC
3 | 1 | 4.7uF | C10 | C0603 | 4.7uF | CL10A475KO8NNNC | SAMSUNG(三星) | C19666 | LCSC | 4.7uF±10%16V
4 | 1 | KT-0603R | LED1 | LED0603-RD |  | KT-0603R | KENTO | C2286 | LCSC | 0603 红灯 高亮
5 | 5 | 4.7K | R1,R2,R3,R4,R5 | R_0603 |  | 0603WAF4701T5E | UniOhm | C23162 | LCSC
6 | 2 | 10K | R9,R10 | R_0603 |  | 0603WAF1002T5E | UniOhm | C25804 | LCSC
7 | 1 | 470Ω | R101 | R0603 | 470Ω | 0603WAF4700T5E | UNI-ROYAL(厚声) | C23179 | LCSC | 470Ω ±1% 100mW 厚膜电阻
8 | 3 | 0Ω | R103,R107,R108 | R0805 | 0Ω | 0805W8F0000T5E | UNI-ROYAL(厚声) | C17477 | LCSC | 厚膜电阻 0Ω ±1% 125mW
9 | 5 | TS-1187A-B-A-B | SW1B1,SW2B1,SW3B1,SW4B1,SW5B1 | SW-SMD_4P-L5.1-W5.1-P3.70-LS6.5-TL-2 |  | TS-1187A-B-A-B | XKB Connectivity(中国星坤) | C318884 | LCSC | 5.1*5.1*1.5mm 立贴 轻触开关

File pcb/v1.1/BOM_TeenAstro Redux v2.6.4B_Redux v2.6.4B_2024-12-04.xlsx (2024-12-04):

No. | Quantity | Comment | Designator | Footprint | Value | Manufacturer Part | Manufacturer | Supplier Part | Supplier | LCSC Part Name
1 | 1 | X4621WVS-2x02I-C40D64 | BRAKE | HDR-SMD_4P-P2.00-V-M-R2-C2-S2.0 |  | X4621WVS-2x02I-C40D64 | XKB Connection(中国星坤) | C917607 | LCSC | 2x2P 间距:2mm 方针
2 | 3 | 1uF | C1,C9,C24 | C0402 | 1uF | CL05A105KA5NQNC | SAMSUNG(三星) | C52923 | LCSC | 1uF ±10% 25V
3 | 7 | 100nF | C2,C3,C6,C13,C20,C30,C37 | C0402 | 100nF | CL05B104KO5NNNC | SAMSUNG(三星) | C1525 | LCSC | 100nF±10%16V
4 | 1 | 10uF | C4 | C0603 | 10uF | GRM188R6YA106MA73D | muRata(村田) | C194427 | LCSC | 10uF ±20% 35V
5 | 4 | 100nF | C5,C19,C23,C39 | C0603 | 100nF | CC0603KRX7R9BB104 | YAGEO(国巨) | C14663 | LCSC | 100nF±10%50V
6 | 2 | 100uF | C7,C21 | CAP-SMD_BD6.3-L6.6-W6.6-RD | 100uF | VEJ101M1VTR-0607 | lelon(立隆) | C176666 | LCSC | 100uF ±20% 35V
7 | 6 | 10uF | C8,C10,C17,C22,C25,C38 | C1206 | 10uF | CL31A106KBHNNNE | SAMSUNG(三星) | C13585 | LCSC | 10uF ±10% 50V
8 | 2 | 470nF | C11,C26 | C0603 | 470nF | CL10B474KA8NNNC | SAMSUNG(三星) | C1623 | LCSC | 470nF ±10% 25V
9 | 2 | 220nF | C12,C27 | C0805 | 220nF | CL21B224KBFNNNE | SAMSUNG(三星) | C5378 | LCSC | 220nF±10%50V
10 | 4 | 10uF | C15,C16,C34,C35 | C0805 | 10uF | CL21A106KAYNNNE | SAMSUNG(三星) | C15850 | LCSC | 10uF ±10% 25V
11 | 2 | 1uF | C18,C36 | C0805 | 1uF | CL21B105KBFNNNE | SAMSUNG(三星) | C28323 | LCSC | 1uF ±10% 50V
12 | 2 | 47uF | C29,C40 | CAP-SMD_L3.2-W1.6 | 47uF | CA45-A-10V-47uF-M | CEC(振华新云) | C688949 | LCSC | 47uF ±20% 10V
13 | 1 | 1nF | C33 | C0402 | 1nF | 0402B102K500NT | FH(风华) | C1523 | LCSC | 1nF ±10% 50V
14 | 4 | 470nF | C41,C42,C43,C44 | C0603 | 470nF | CL10A474KB8NNNC | SAMSUNG(三星) | C170149 | LCSC | 470nF ±10% 50V
15 | 1 | {ManufacturerPart!} | CN1 | AUDIO-SMD_PJ-327E-SMT |  | PJ-327E-SMT | XKBConnectivity(中国星坤) | C319105 | LCSC | 3.5mm耳机座5P
16 | 1 | USB_C | CN2 | USB-C-SMD_TYPE-C-USB-18 |  | 105450-0101 | MOLEX | C134092 | LCSC
17 | 2 | {ManufacturerPart!} | D1,D2 | SOT-363_L2.0-W1.3-P0.65-LS2.1-TL |  | BAV99S,115 | Nexperia(安世) | C96225 | LCSC | BAV99S,115
18 | 1 | 1N5819WS | D3 | SOD-323_L1.8-W1.3-LS2.5-RD |  | 1N5819WS | Hottech(合科泰) | C191023 | LCSC | 电压:40V 电流:1A
19 | 1 | SS34 | D6 | SMA_L4.3-W2.6-LS5.2-RD |  | SS34 | MDD(辰达半导体) | C8678 | LCSC | 电压:40V 电流:3A
20 | 1 | DC-005-5A-2.0 | DC1 | DC-IN-TH_DC-005-5A-2.0 |  | DC-005-5A-2.0 | XKB Connection(中国星坤) | C381116 | LCSC | DC电源插座 内径:2mm 外径:6.2mm
21 | 1 | U.FL-R-SMT-1(80) | JP1 | RF-SMD_FRF05002-JSS103M |  | U.FL-R-SMT-1(80) | HRS(广濑) | C88374 | LCSC | IPEX 内针
22 | 1 | 47nH | L1 | IND-SMD_L1.6-W0.8-1 | 47nH | LQW18AN47NJ00D | muRata(村田) | C98077 | LCSC | LQW18AN47NJ00D
23 | 2 | 10uH | L2,L3 | IND-SMD_L2.5-W2.0_SWPA252012S | 10uH | SWPA252012S100MT | Sunlord(顺络) | C37428 | LCSC | 10uH ±20% 880mA
24 | 1 | KT-0603W | LED1 | LED0603-R-RD_WHITE |  | KT-0603W | KENTO | C2290 | LCSC | 0603 白灯 高亮
25 | 1 | KT-0603R | LED2 | LED0603-RD |  | KT-0603R | KENTO | C2286 | LCSC | 0603 红灯 高亮
26 | 2 | TMC2660-PA | M1,M2 | PQFP44_WITH_PADS |  | TMC2660C-PA-T | TMC2660C-PA-T | C2927052 | LCSC
27 | 1 | RA/AZ | MOT1 | CONN-TH_DB125-3.5-4P-GN |  | DB125-3.5-4P-GN-S | DIBO(地博电气) | C2757925 | LCSC | 3.5mm排数:1每排P数:4直针
28 | 1 | DEC/ALT | MOT2 | CONN-TH_DB125-3.5-4P-GN |  | DB125-3.5-4P-GN-S | DIBO(地博电气) | C2757925 | LCSC | 3.5mm排数:1每排P数:4直针
29 | 1 | Plot M.2 | MX1 | SMD_BD5.6-D4.1 |  | SMTSO3030CTJ | Sinhoo(雄和远景) | C2915308 | LCSC | M3贴片螺母铜镀锡铜镀锡
30 | 4 | 1.5kΩ | R1,R2,R10,R11 | R0603 | 1.5kΩ | 0603WAF1501T5E | UNI-ROYAL(厚声) | C22843 | LCSC | 1.5kΩ±1%100mW
31 | 4 | 3kΩ | R3,R4,R13,R14 | R0603 | 3kΩ | 0603WAF3001T5E | UNI-ROYAL(厚声) | C4211 | LCSC | 3kΩ±1%100mW
32 | 2 | 5.1kΩ | R5,R9 | R0603 | 5.1kΩ | 0603WAF5101T5E | UNI-ROYAL(厚声) | C23186 | LCSC | 5.1kΩ ±1% 100mW 厚膜电阻
33 | 2 | 10kΩ | R6,R18 | R0402 | 10kΩ | 0402WGF1002TCE | UNI-ROYAL(厚声) | C25744 | LCSC | 10kΩ ±1% 62.5mW 厚膜电阻
34 | 2 | 22Ω | R7,R8 | R0402 | 22Ω | 0402WGF220JTCE | UNI-ROYAL(厚声) | C25092 | LCSC | 22Ω ±1% 62.5mW 厚膜电阻
35 | 2 | 150Ω | R12,R35 | R0603 | 150Ω | 0603WAF1500T5E | UNI-ROYAL(厚声) | C22808 | LCSC | 150Ω ±1% 100mW 厚膜电阻
36 | 1 | 1kΩ | R17 | R0603 | 1kΩ | 0603WAF1001T5E | UNI-ROYAL(厚声) | C21190 | LCSC | 1kΩ ±1% 100mW 厚膜电阻
37 | 4 | 75mΩ | R20,R23,R26,R28 | R1210 | 75mΩ | RTT12R075FTP | RALEC(旺诠) | C333258 | LCSC | 厚膜电阻 75mΩ ±1% 500mW
38 | 4 | 10Ω | R21,R22,R27,R29 | R0603 | 10Ω | 0603WAF100JT5E | UNI-ROYAL(厚声) | C22859 | LCSC | 10Ω ±1% 100mW 厚膜电阻
39 | 1 | 33kΩ | R31 | R0603 | 33kΩ | 0603WAF3302T5E | UNI-ROYAL(厚声) | C4216 | LCSC | 33kΩ ±1% 100mW 厚膜电阻
40 | 1 | 255kΩ | R32 | R0603 | 255kΩ | RC0603FR-07255KL | YAGEO(国巨) | C295887 | LCSC | 厚膜电阻 255kΩ ±1% 100mW
41 | 1 | MICROMOD-Teensy4 | U1 | M.2-CONNECTOR-E |  | AS0BC21-S48BE-7H | Foxconn | C2761457 | LCSC
42 | 1 | {ManufacturerPart!} | U3 | GPSM-SMD_ATGM336H-TR |  | ATGM336H-5N31 | 杭州中科微 | C90770 | LCSC | BDS/GNSS全星座定位导航模块
43 | 1 | AP63205WU-7 | U7 | TSOT-23-6_L2.9-W1.6-P0.95-LS2.8-BL |  | AP63205WU-7 | DIODES(美台) | C2071056 | LCSC | AP63205WU-7
44 | 1 | DPS1135FIA-13 | U8 | QFN-17_L4.0-W4.0-P0.50-TL-EP |  | DPS1135FIA-13 | DIODES(美台) | C2150216 | LCSC | DPS1135FIA-13
45 | 1 | AP63203WU-7 | U9 | TSOT-26_L2.9-W1.6-P0.95-LS2.8-BL |  | AP63203WU-7 | DIODES(美台) | C780769 | LCSC | AP63203WU-7

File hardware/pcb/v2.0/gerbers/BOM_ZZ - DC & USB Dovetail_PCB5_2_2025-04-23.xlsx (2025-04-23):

No. | Quantity | Comment | Designator | Footprint | Value | Manufacturer Part | Manufacturer | Supplier Part | Supplier | LCSC Part Name
1 | 1 | USB_C | CN2 | USB-C-SMD_TYPE-C-USB-18 |  | 105450-0101 | MOLEX | C134092 | LCSC
2 | 2 | 5.1kΩ | R5,R9 | R0603 | 5.1kΩ | 0603WAF5101T5E | UNI-ROYAL(厚声) | C23186 | LCSC | 5.1kΩ ±1% 100mW 厚膜电阻

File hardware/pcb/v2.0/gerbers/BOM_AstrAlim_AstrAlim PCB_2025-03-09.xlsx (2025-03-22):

No. | Quantity | Comment | Designator | Footprint | Value | Manufacturer Part | Manufacturer | Supplier Part | Supplier | LCSC Part Name
1 | 3 | 10uF | C4,C5,C21 | C0805 | 10uF | CL21A106KAYNNNE | SAMSUNG(三星) | C15850 | LCSC | 10uF ±10% 25V
2 | 2 | 4.7uF | C6,C22 | C0805 | 4.7uF | CL21A475KAQNNNE | SAMSUNG(三星) | C1779 | LCSC | 4.7uF ±10% 25V
3 | 6 | 10nF | C7,C8,C9,C23,C24,C25 | C0402 | 10nF | CL05B103KB5NNNC | SAMSUNG(三星) | C15195 | LCSC | 10nF ±10% 50V
4 | 4 | 47uF | C10,C11,C26,C27 | CAP-SMD_L3.5-W2.8-R-RD | 47uF | CA45-B-16V-47uF-K | CEC(振华新云) | C136751 | LCSC | 47uF ±10% 16V
5 | 2 | 2.2nF | C12,C28 | C0603 | 2.2nF | 0603B222K500NT | FH(风华) | C1604 | LCSC | 2.2nF ±10% 50V
6 | 2 | 22pF | C13,C29 | C0402 | 22pF | 0402CG220J500NT | FH(风华) | C1555 | LCSC | 22pF ±5% 50V
7 | 6 | 100nF | C16,C19,C20,C30,C32,C38 | C0402 | 100nF | CL05B104KO5NNNC | SAMSUNG(三星) | C1525 | LCSC | 100nF ±10% 16V
8 | 5 | 22uF | C34,C35,C39,C40,C41 | C0805 | 22uF | CL21A226MAQNNNE | SAMSUNG(三星) | C45783 | LCSC | 22uF ±20% 25V
9 | 2 | SS54 | D1,D3 | SMA_L4.4-W2.8-LS5.4-R-RD |  | SS54 | MDD | C22452 | LCSC | 电压:40V 电流:5A
10 | 1 | MM1Z15 | D2 | SOD-123_L2.7-W1.6-LS3.6-RD |  | MM1Z15 | 宏嘉诚 | C22379462 | LCSC | MM1Z15
11 | 2 | BAV99S,115 | D4,D5 | SOT-363_L2.0-W1.3-P0.65-LS2.1-TL |  | BAV99S,115 | Nexperia(安世) | C96225 | LCSC | 电压:100V 电流:200mA
12 | 5 | 1812L300/16GR | F5,F6,F7,F8,F10 | F1812 |  | 1812L300/16GR | LUTE(陆特) | C18198349 | LCSC | 16V 3A 自恢复保险丝
13 | 2 | Test-Point | GN0,WP0 | test-point-0.5mm
14 | 1 | FH-00369 | H2 | CONN-SMD_FH-00369 |  | FH-00369 | Liansheng(连盛) | C2685115 | LCSC | 间距:2.54mm 2x20P 立贴
15 | 1 | BWU.FL-IPEX1 | JP1 | IPEX-SMD_BWIPX-1-001E |  | BWU.FL-IPEX1 | BAT WIRELESS(蝙蝠无线) | C5137195 | LCSC | 内针 IPEX
16 | 1 | 47nH | L1 | IND-SMD_L1.6-W0.8-1 | 47nH | LQW18AN47NJ00D | muRata(村田) | C98077 | LCSC | LQW18AN47NJ00D
17 | 5 | NCD0805R1 | LED1,LED2,LED3,LED4,LED5 | LED0805-R-RD |  | NCD0805R1 | 国星光电 | C84256 | LCSC | 红灯 0805红灯 正贴
18 | 1 | DMMT5401-7-F | Q1 | SOT-23-6_L2.9-W1.6-P0.95-LS2.8-BR |  | DMMT5401-7-F | DIODES(美台) | C154733 | LCSC | 耐压:150V 电流:200mA 2个PNP
19 | 1 | AP2317A | Q2 | SOT-23-3_L2.9-W1.6-P1.90-LS2.8-BR |  | AP2317A | ALLPOWER(铨力) | C2828580 | LCSC | P沟道 耐压:20V 电流:6A
20 | 1 | DMTH4004LK3-13 | Q3 | TO-252-2_L6.6-W6.1-P4.58-LS9.9-TL |  | DMTH4004LK3-13 | DIODES(美台) | C260930 | LCSC | N沟道 耐压:40V 电流:100A
21 | 5 | NCE30P12S | Q4,Q8,Q9,Q10,Q14 | SOIC-8_L4.9-W3.9-P1.27-LS6.0-BL |  | NCE30P12S | NCE(无锡新洁能) | C167515 | LCSC | 1个P沟道 耐压:30V 电流:12A
22 | 6 | MMBT3904 | Q7,Q11,Q15,Q16,Q19,Q20 | SOT-23-3_L2.9-W1.3-P1.90-LS2.4-BR |  | MMBT3904 | CJ(江苏长电/长晶) | C20526 | LCSC | NPN 电流:200mA 耐压:40V hfe=100~300
23 | 13 | 10kΩ | R6,R7,R16,R20,R40,R48,R54,R56,R67,R86,R87,R93,R94 | R0402 | 10kΩ | 0402WGF1002TCE | UNI-ROYAL(厚声) | C25744 | LCSC | 10kΩ ±1% 62.5mW 厚膜电阻
24 | 2 | 665kΩ | R10,R32 | R0603 | 665kΩ | AC0603FR-07665KL | YAGEO(国巨) | C228009 | LCSC | 665kΩ ±1% 100mW
25 | 1 | 130kΩ | R11 | R0603 | 130kΩ | 0603WAF1303T5E | UNI-ROYAL(厚声) | C22795 | LCSC | 130kΩ ±1% 100mW 厚膜电阻
26 | 2 | 39kΩ | R12,R34 | R0603 | 39kΩ | 0603WAF3902T5E | UNI-ROYAL(厚声) | C23153 | LCSC | 39kΩ ±1% 100mW 厚膜电阻
27 | 12 | 1kΩ | R17,R21,R22,R27,R30,R41,R42,R49,R50,R53,R55,R91 | R0402 | 1kΩ | 0402WGF1001TCE | UNI-ROYAL(厚声) | C11702 | LCSC | 1kΩ ±1% 62.5mW 厚膜电阻
28 | 1 | 470kΩ | R18 | R0603 | 470kΩ | 0603WAF4703T5E | UNI-ROYAL(厚声) | C23178 | LCSC | 470kΩ ±1% 100mW 厚膜电阻
29 | 1 | 4.7kΩ | R19 | R0402 | 4.7kΩ | 0402WGF4701TCE | UNI-ROYAL(厚声) | C25900 | LCSC | 4.7kΩ ±1% 62.5mW 厚膜电阻
30 | 5 | 10mΩ | R23,R26,R29,R43,R51 | R1206 | 10mΩ | FMF06FTHR010-LH | PSA(信昌电陶) | C105362 | LCSC | 10mΩ ±1% 1W 合金电阻
31 | 1 | 82kΩ | R33 | R0603 | 82kΩ | 0603WAF8202T5E | UNI-ROYAL(厚声) | C23254 | LCSC | 82kΩ ±1% 100mW 厚膜电阻
32 | 1 | 47kΩ | R59 | R0402 | 47kΩ | 0402WGF4702TCE | UNI-ROYAL(厚声) | C25792 | LCSC | 47kΩ ±1% 62.5mW 厚膜电阻
33 | 4 | 5.1kΩ | R61,R62,R64,R65 | R0603 | 5.1kΩ | 0603WAF5101T5E | UNI-ROYAL(厚声) | C23186 | LCSC | 5.1kΩ ±1% 100mW 厚膜电阻
34 | 1 | 680Ω | R88 | R0603 | 680Ω | 0603WAF6800T5E | UNI-ROYAL(厚声) | C23228 | LCSC | 680Ω ±1% 100mW 厚膜电阻
35 | 2 | 3.9kΩ | R89,R90 | R0603 | 3.9kΩ | 0603WAF3901T5E | UNI-ROYAL(厚声) | C23018 | LCSC | 3.9kΩ ±1% 100mW 厚膜电阻
36 | 1 | 750Ω | R92 | R0603 | 750Ω | 0603WAF7500T5E | UNI-ROYAL(厚声) | C23241 | LCSC | 750Ω ±1% 100mW 厚膜电阻
37 | 2 | 2kΩ | R95,R96 | R0402 | 2kΩ | 0402WGF2001TCE | UNI-ROYAL(厚声) | C4109 | LCSC | 2kΩ ±1% 62.5mW 厚膜电阻
38 | 1 | 470Ω | R97 | R0603 | 470Ω | 0603WAF4700T5E | UNI-ROYAL(厚声) | C23179 | LCSC | 470Ω ±1% 100mW 厚膜电阻
39 | 1 | K3-1204D-L | SW1 | SW-TH_K3-1204D-L |  | K3-1204D-L | 韩国韩荣 | C2909229 | LCSC | 卧插双档 滑动开关
40 | 1 | DSHP02TSGER | SW2 | SW-SMD_DSHP02TSGER |  | DSHP02TSGER | 康深 | C3293142 | LCSC | 2位 1.27mm间距贴片型 KE拨码开关 编码开关
41 | 1 | ATGM336H-6N-74 | U3 | COMM-SMD_18P-L10.1-W9.7-P1.1-TL_L76-LB |  | ATGM336H-6N-74 | 杭州中科微 | C5804601 | LCSC | ATGM336H-6N-74
42 | 2 | TPS54531DDAR | U5,U12 | SOIC-8_L5.0-W4.0-P1.27-LS6.0-BL-EP2.0 |  | TPS54531DDAR | TI(德州仪器) | C50605 | LCSC | TPS54531DDAR
43 | 2 | 4.7uH | U6,U13 | IND-SMD_L7.3-W6.6 | 4.7uH | MDA7050-4R7M | KOHERelec(科或) | C2847541 | LCSC | 4.7uH ±20% 8.8A
44 | 5 | INA219AIDR | U18,U19,U20,U21,U22 | SOIC-8_L4.9-W3.9-P1.27-LS6.0-BL |  | INA219AIDR | TI(德州仪器) | C138706 | LCSC | 零漂移双向电流/功率监测器带I2C接口
45 | 1 | AT24C32D-SSHM-T | U23 | SOIC-8_L5.0-W4.0-P1.27-LS6.0-BL |  | AT24C32D-SSHM-T | MICROCHIP(美国微芯) | C60583 | LCSC | AT24C32D-SSHM-T

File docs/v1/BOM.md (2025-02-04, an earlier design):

# Bill of Materials
Standard hardware parts are listed below without links; these can be ordered from any hardware supplier--a hardware assortment from Amazon, Aliexpress, or some other source is recommended.
## Mount
| Index | Name | Quantity | Reference | Price € | Total (€) | Link |
| --- | --- | --- | --- | --- | --- | --- |
| D01 | Harmonic Drive | 2 | HBS-17, Reduction ratio 100 | 70 | 140 | [Aliexpress](https://www.aliexpress.com/item/1005007101363756.html)
| D02 | Bearing  | 2 |  18307RS  | 1 | 2 | [Aliexpress](https://www.aliexpress.com/item/1005006822711801.html)
| D03 | Bearing | 2 | 678ZZ | US$3.75/5 | | [Aliexpress](https://www.aliexpress.us/item/1005003884980951.html)|
| D04 | TA6212Z 62x74x12 | 2 | TA6212Z 62x74x12 | 5 | 10 | [Aliexpress](https://www.aliexpress.com/item/1005006993881258.html)
| D05 | 20x20 Alu profile | 3 | 20x20x100mm | 3,5 | 10,5 | [Aliexpress](https://www.aliexpress.com/item/1005002537611699.html)
| D06 | 20x20 Alu profile rounded | 1 | 2020R 20x20x100mm | 1 | 1 | [Aliexpress](https://www.aliexpress.com/item/1005004571007033.html)
| D07 | Nema 17 brake | 1 | SWB-01 | 34 | 34 | [StepperOnline](https://www.omc-stepperonline.com/fr/dc-frein-electromagnetique-24v-0-25nm-35-4oz-in-pour-nema-17-moteur-pas-a-pas-swb-01)
| D08 | Nema 17 0.9° double shaft | 1 | 17HS15-1684D-MG10  | 15 | 15 | [StepperOnline](https://www.omc-stepperonline.com/dual-shaft-nema-17-bipolar-0-9deg-44ncm-62-48oz-in-1-68a-2-8v-42x42x48mm-4-wires-17hm19-1684d)
| D09 | Nema 17 0.9° single shaft | 1 | 17HS15-1684S-MG10  | 15 | 15 | [StepperOnline](https://www.omc-stepperonline.com/nema-17-bipolar-0-9deg-44ncm-62-3oz-in-1-68a-2-8v-42x42x47mm-4-wires-17hm19-1684s)
| D10 | Stainless Steel Cylindrical Locating Dowel | 2 | M8x45mm | 1,5 | 3 | [Aliexpress](https://www.aliexpress.com/item/1005007181161819.html)
| D11 | GT2 Pulley | 2 | 5mm hole, 6mm width - 16T | US$0.99 | US$1.98 | [Aliexpress](https://www.aliexpress.us/item/1005006251245390.html) |
| D12 | GT2 Pulley | 1 | 8mm hole, 6mm width - 60T | US$3.93 | | [Aliexpress](https://www.aliexpress.us/item/1005007680675119.html) |
| D13 | GT2 Pulley | 1 | 8mm hole, 6mm width - 80T | US$3.71 | | [Aliexpress](https://www.aliexpress.us/item/1005006150326586.html) |
| D14 | GT2 Belt | 1 | 150mm (154mm optional) | US$1.57 | | [Aliexpress](https://www.aliexpress.us/item/1005004100120790.html) |
| D15 | GT2 Belt | 1 | 200mm (180mm optional) | US$0.99 | | [Aliexpress](https://www.aliexpress.us/item/32477498985.html) |
| D16 | Hex Brass Male Female | 4 | M3x20x6 FM | 0,2 | 0,8 | [Aliexpress](https://www.aliexpress.com/item/1005005462128073.html)
| D17 | Hex Brass Male Female | 4 | M3x25x6 FM | 0,25 | 1 | [Aliexpress](https://www.aliexpress.com/item/1005005462128073.html)
| D18 | Brass Standoffs Hex | 4 | M3x8 FF | 0,08 | 0,32 | [Aliexpress](https://www.aliexpress.com/item/1005006049595637.html)
| D19 | Handle | 1 | Mentor 3270.0883 | | | | [Newark](https://www.newark.com/mentor/3270-0883/handle-steel-88mm-ctrs-black/dp/15J5728) |
| D20 | Washer M8x10x1 | 2 | M8x10x1 | 0,02 | 0,04 | [Aliexpress](https://www.aliexpress.com/item/1005006924477321.html)
| D21 | T-nuts | 4 |  T-nut 2020 M4 | 0,05 | 0,2 | [Aliexpress](https://www.aliexpress.com/item/32964780472.html)
| D22 | T-nuts | 22 |  T-nut 2020 M5  | 0,07 | 1,4 | [Aliexpress](https://www.aliexpress.com/item/32964780472.html)
| D23 | GPS Antenna, U.FL. | 1 | 25x25mm, 10cm cable | | | [Aliexpress](https://www.aliexpress.us/item/1005007545390748.html) |
| D24 | Finder scope support | 1 | Neewer LS-15 | | | | |
| D25 | Vixen/Losmandy Dovetail Clamp | 1 | | US$47.75 | | [Aliexpress](https://www.aliexpress.us/item/3256805685939886.html) |
| | SS SHCS M3x10 | 25 | | | | Any hardware source |
| | SS SHCS M3x6 | 17 | | | | Any hardware source |
| | SS SHCS M4x10 | 8 | | | | Any hardware source |
| | SS SHCS M4x16 | 12 | | | | Any hardware source |
| | SS SHCS M6x10 | 6 | | | | Any hardware source |
| | SS M3 thin nut | 4 | | | | Any hardware source |
| | SS M4 thin nut | 4 | | | | Any hardware source |
| | SS BHCS M4x12 | 10 | | | | Any hardware source |
| | SS BHCS M4x6 | 6 | | | | Any hardware source |
| | SS BHCS M5x10 | 16 | | | | Any hardware source |
| | SS BHCS M5x25 | 2 | | | | Any hardware source |
| | SS BHCS M5x8 | 10 | | | | Any hardware source |
| | SS BHCS M6x16 | 8 | | | | Any hardware source |
| | CNC parts  | 18 |  -  | 330 HT  | 330 HT  |  [JLC3DP](https://jlcpcb.com/)

Abbreviations:
* `SS`: Stainless Steel
* `BHCS`: Button-Head Cap Screw
* `SHCS`: Socket-Head Cap Screw

## Base
| Index | Name | Quantity | Reference | Price € | Total (€) | Link |
| --- | --- | --- | --- | --- | --- | --- |
| D26 | Barrel Nut | 1 | M6x20 | 2 | 2 | [Aliexpress](https://www.aliexpress.com/item/1005005881148659.html)
| D27 | Fixing Ring | 1 | SOH6 6x12x6mm | 1 | 1 | [Aliexpress](https://www.aliexpress.com/item/1005004569679247.html)
| D28 | Adjustable Handle Lever | 1 | M6 | 1,7 | 1,7 | [Aliexpress](https://www.aliexpress.com/item/4000304505877.html)
| D29 | Clamping knob | 2 | M6, 15mm | US$2.68 | US$5.36 | [Aliexpress](https://www.aliexpress.us/item/3256804357384499.html) |
| D30 | Clamping knob | 2 | M6, 30mm | US$3.28 | US$6.56 | [Aliexpress](https://www.aliexpress.us/item/3256804357384499.html) |
| D31 | Clamping knob | 1 | M6, 40mm | US$3.68 | US$3.68 | [Aliexpress](https://www.aliexpress.us/item/3256804357384499.html) |
| D32 | Hexagonal socket head cap screw | 1 | M6 shoulder dia 8mm, 60mm | 1,8 | 1,8 | [Aliexpress](https://www.aliexpress.com/item/1005006435736666.html) |
| D33 | Round magnet, 3 x 3mm | 2 | Neodymium | | | |
| D34 | 5mm hex wrench | 1 | | | | |
| | SS SHCS M6x10 | 5 | | | | |
| | SS SHCS M4x12 | 3 | | | | |
| | SS SHCS M5x14 | 4 | | | | |

## Electronics
| Index | Name | Quantity | Reference | Price € | Total (€) | Link |
| --- | --- | --- | --- | --- | --- | --- |
| | Electronics TeenAstro | 1 |  - | 50 HT | 50 HT |  [JLCPCB](https://jlcpcb.com/)
| PCB01 | Brake Driver | 1 | | | | | |
| PCB02 | ESP-01S | 1 | | US$1.68 | | [Aliexpress](https://www.aliexpress.us/item/1005007994226271.html) |
| PCB03 | TeenAstro Redux | 1 | | | | | |
| PCB04 | Teensy 4 MicroMod | 1 | | US$21.50 | | [SparkFun](https://www.sparkfun.com/sparkfun-micromod-teensy-processor.html) |
| U1 | Wemos D1 Mini 4.0 | 1 | | US$4.13 | | [Aliexpress](https://www.aliexpress.us/item/2251832342786284.html) |
| Display | 2.42" I2C OLED Display | 1 | | US$6.90 | | [Aliexpress](https://www.aliexpress.us/item/3256806159669161.html) | 
| | Power Switch for main board | 1 | | US$3.14 | | [Newark](https://www.newark.com/multicomp/4us1r102m7rn/switch-rocker-spdt-20v-black/dp/95M2277) |

Order PCBs for this project (PCB01, PCB03, and the SHC PCB) assembled through [OSHWLab](https://oshwlab.com/lordzurp/teenastro-redux).  Be aware that as of this writing (3 Feb 25), the main PCB layout has a bug; the locating holes for the Teensy MicroMod socket need to be 1.6mm and 1.1mm diameter (double their present size in each case).

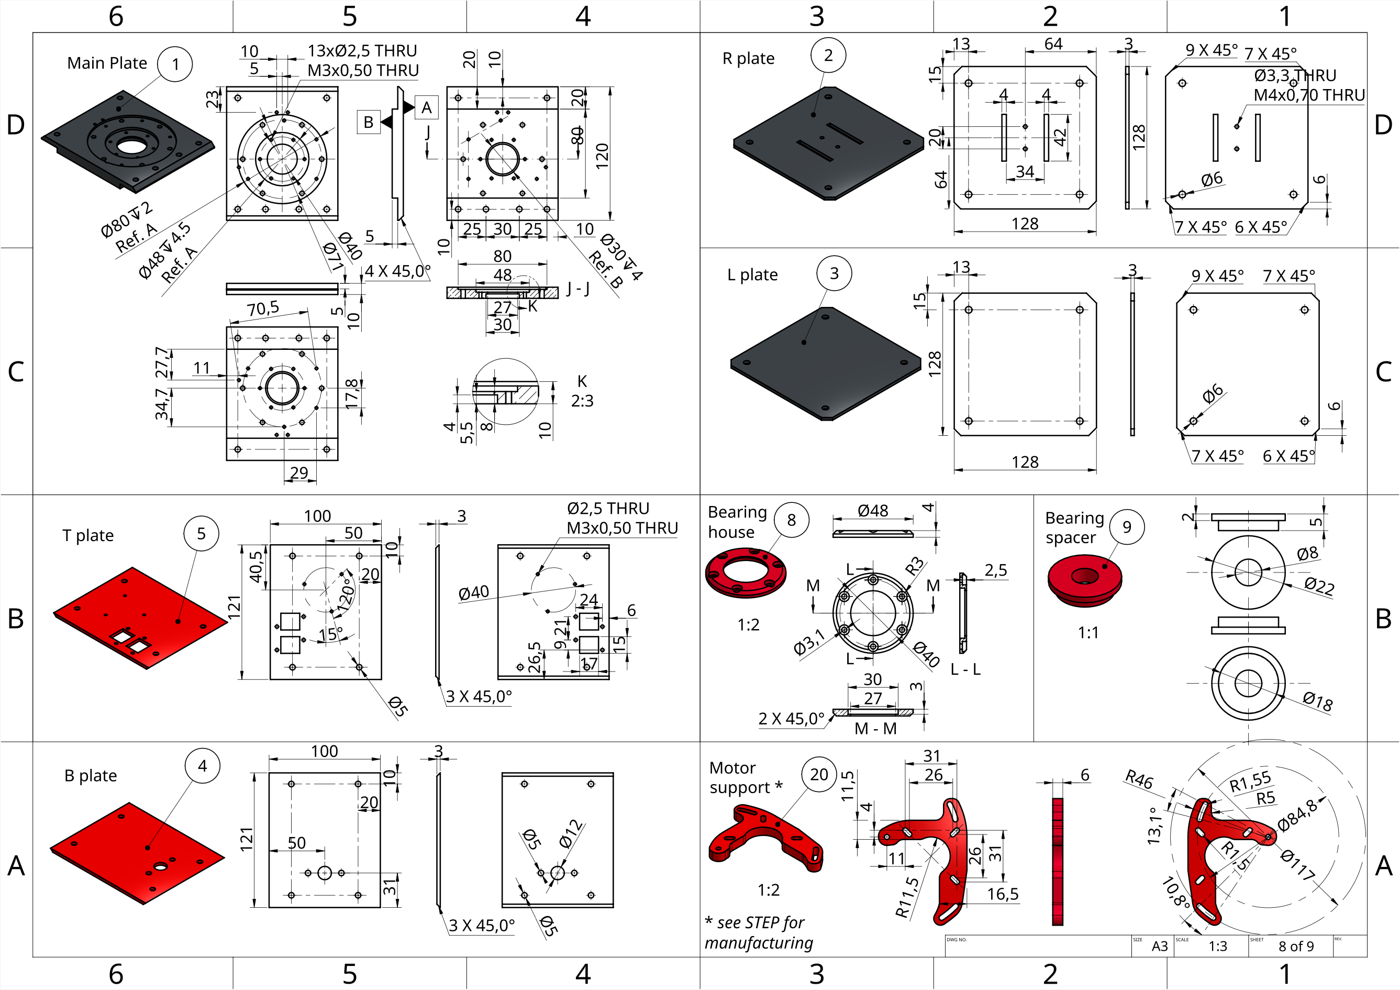
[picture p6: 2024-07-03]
images/HEMY_parts_1.png

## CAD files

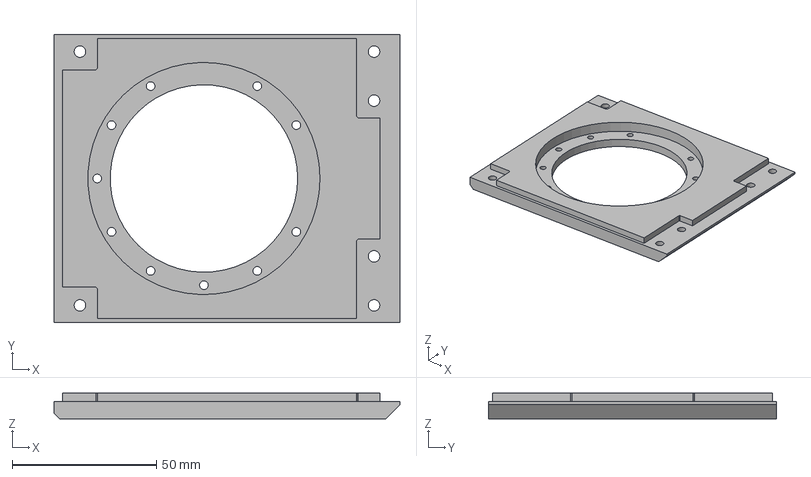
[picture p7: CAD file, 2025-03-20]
hardware/step/v2.0/HEMY2 - Main frame B.step
120.0 x 100.0 x 9.00 mm

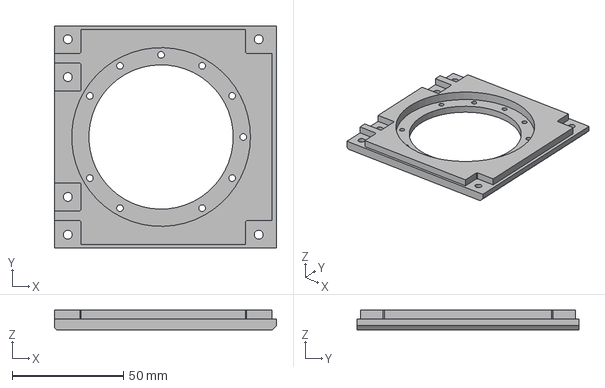
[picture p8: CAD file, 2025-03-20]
hardware/step/v2.0/HEMY2 - Main frame A.step
100.0 x 100.0 x 9.00 mm

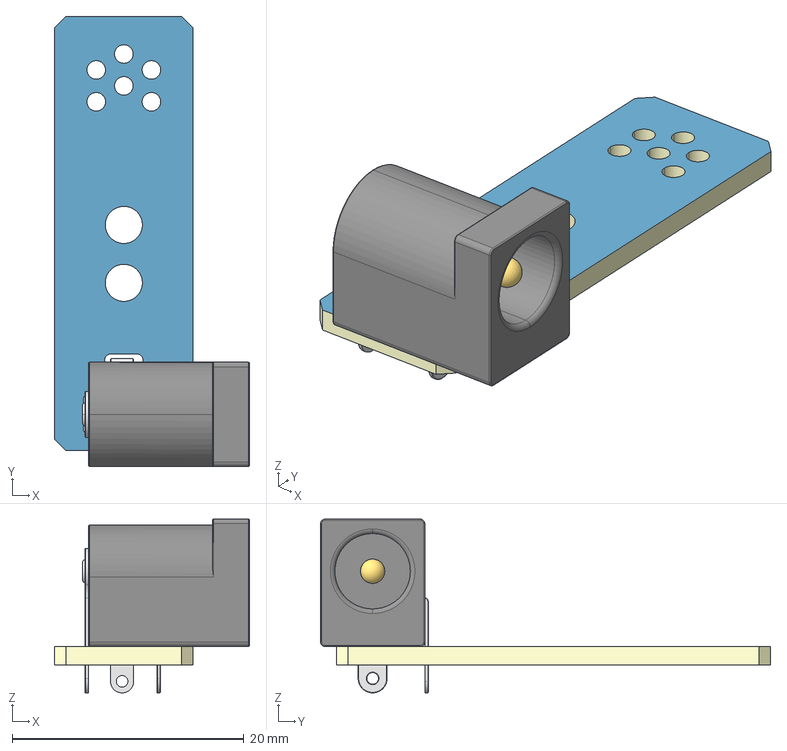
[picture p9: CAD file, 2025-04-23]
hardware/pcb/v2.0/gerbers/3D_PCB5_1_2025-04-23.step
16.8 x 38.8 x 15.0 mm
3ftF-TopTrack
3ftF-BottomTrack
3ftF-Board
3ftF-Top FPC Stiffener
3ftF-Bot FPC Stiffener
3ftF-DC1-DC-IN-TH_DC-005-5A-2.0

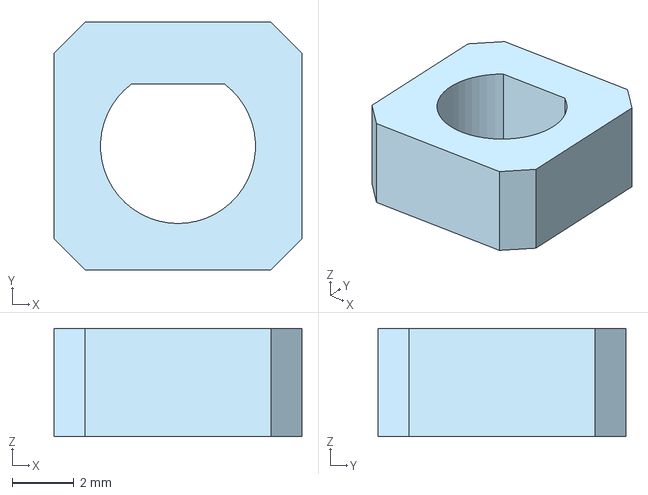
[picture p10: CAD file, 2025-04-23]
hardware/step/v2.0/HEMY2 - SWB-003-shaft coupling.step
8.00 x 8.00 x 3.50 mm

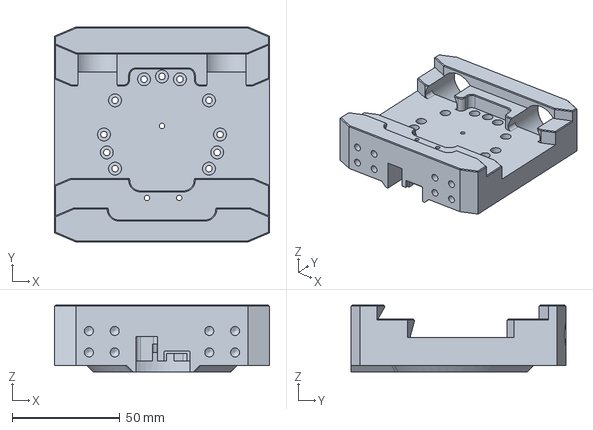
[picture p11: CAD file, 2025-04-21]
hardware/step/v2.0/HEMY2 - Dovetail.step
100.0 x 100.0 x 31.0 mm

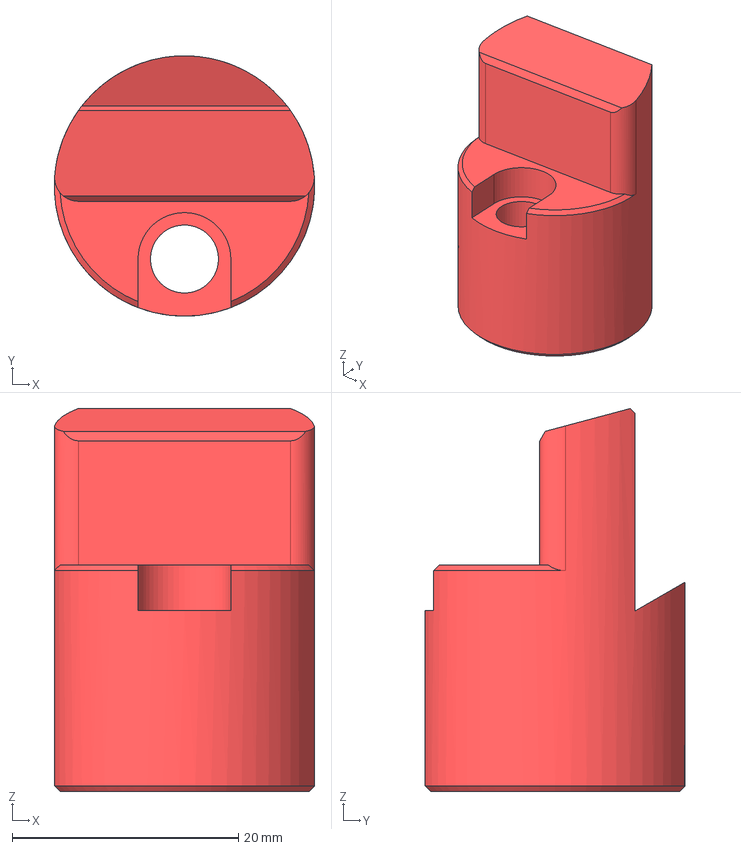
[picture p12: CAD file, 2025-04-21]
hardware/step/v2.0/HEMY2 - Dovetail Fix.step
23.0 x 23.0 x 33.8 mm

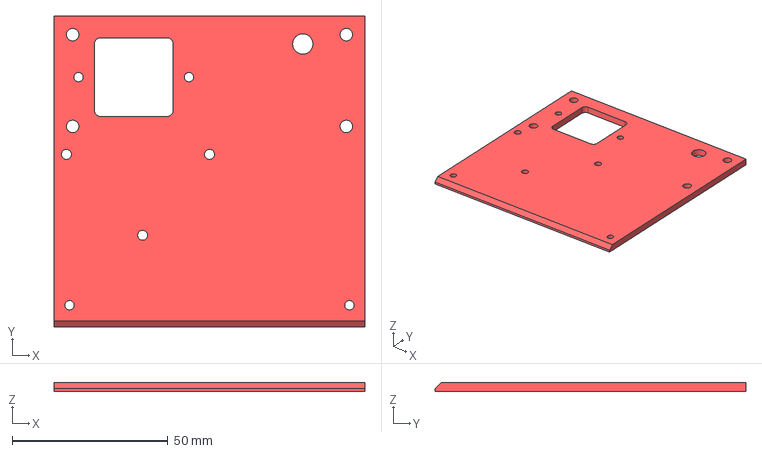
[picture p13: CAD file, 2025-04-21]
hardware/step/v2.0/HEMY2 - Top plate.step
100.0 x 100.0 x 3.00 mm

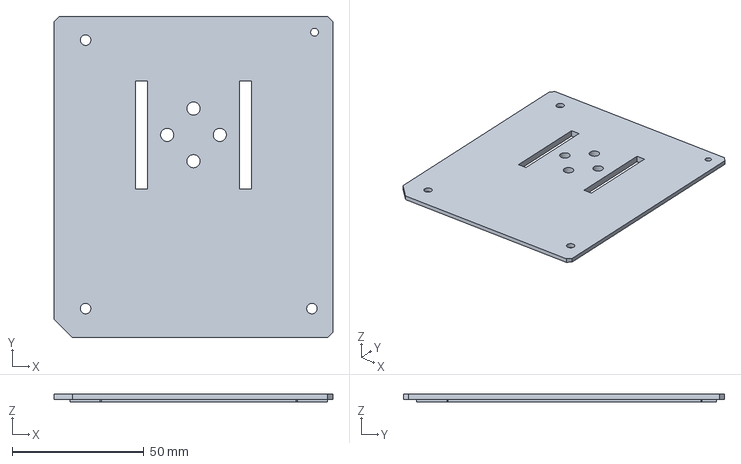
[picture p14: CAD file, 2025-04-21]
hardware/step/v2.0/HEMY2 - Lateral A.step
106.0 x 122.0 x 3.00 mm

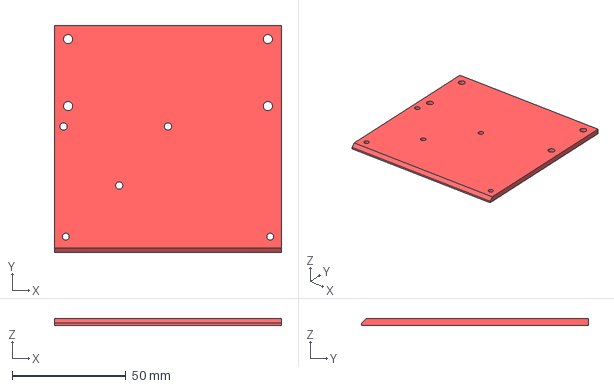
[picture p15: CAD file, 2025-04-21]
hardware/step/v2.0/HEMY2 - Top plate without antennas.step
100.0 x 100.0 x 3.00 mm

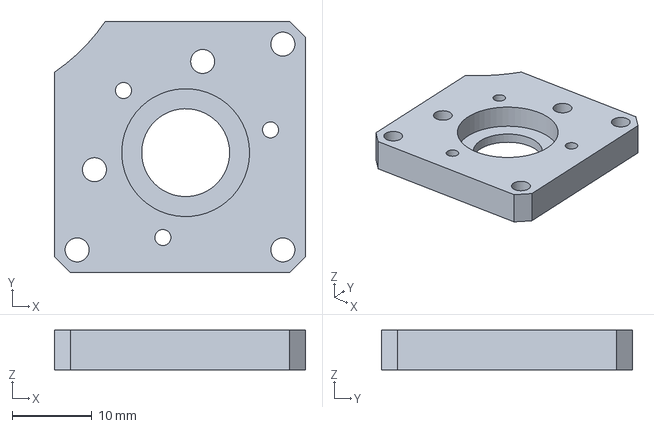
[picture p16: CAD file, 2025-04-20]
hardware/step/v2.0/HEMY2 - Brake support.step
31.4 x 31.4 x 5.00 mm

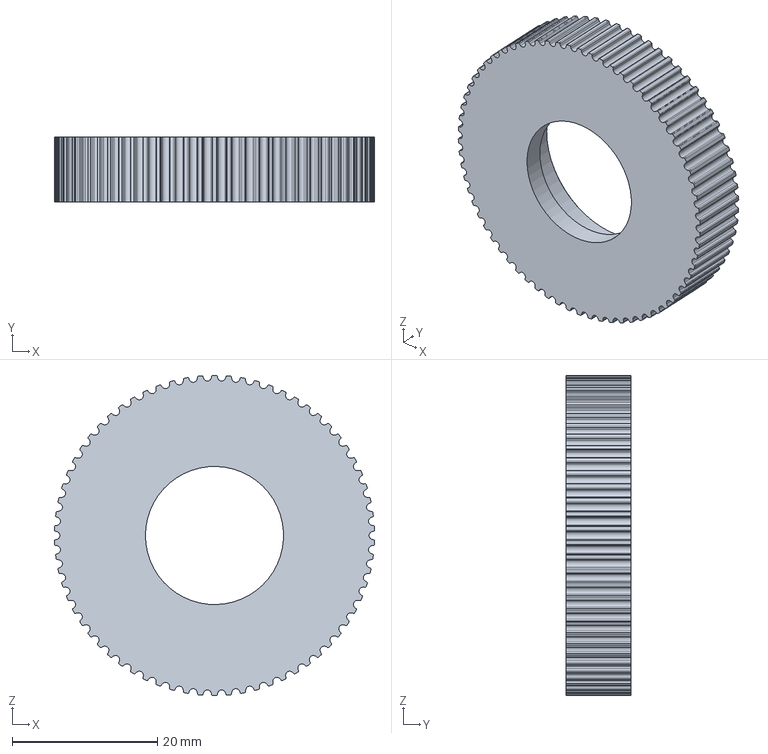
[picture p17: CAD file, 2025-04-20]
hardware/step/v2.0/HEMY2 - Pulley 70Ts CNC.step
44.0 x 9.00 x 44.1 mm

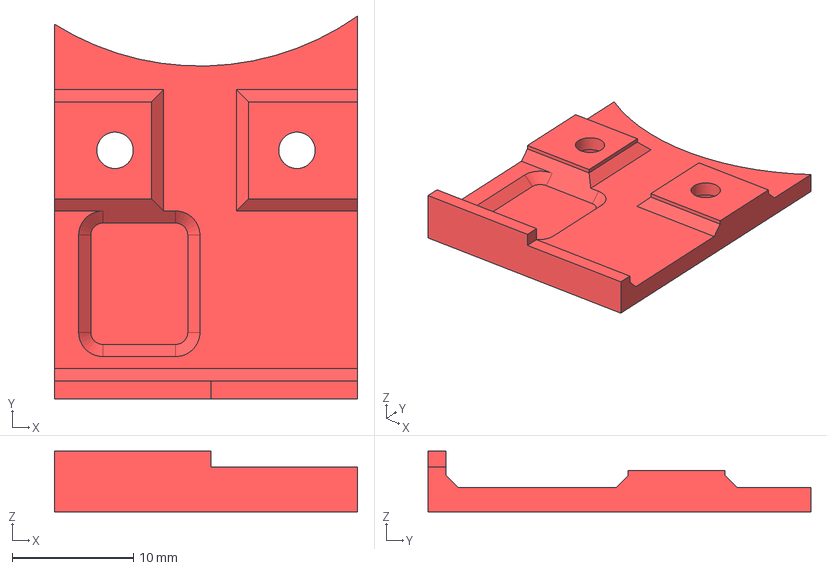
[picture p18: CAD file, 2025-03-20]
hardware/step/v2.0/HEMY2 - I3D - Dovetail PCB cover.step
25.0 x 31.6 x 5.00 mm

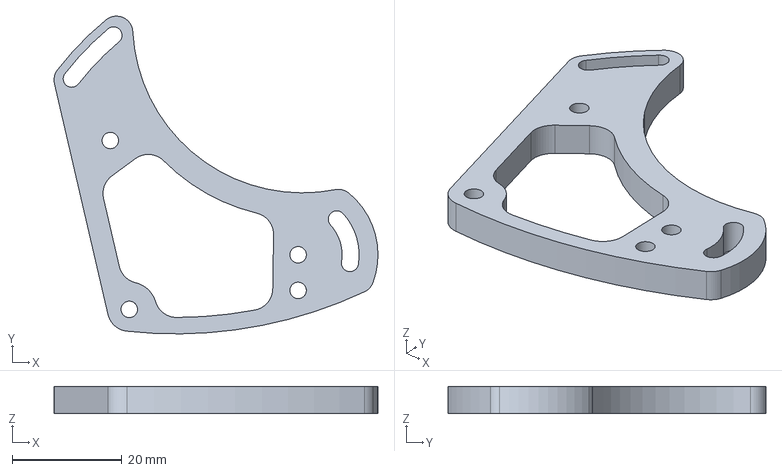
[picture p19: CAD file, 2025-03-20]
hardware/step/v2.0/HEMY2 - Motor Support.step
59.1 x 58.0 x 5.00 mm

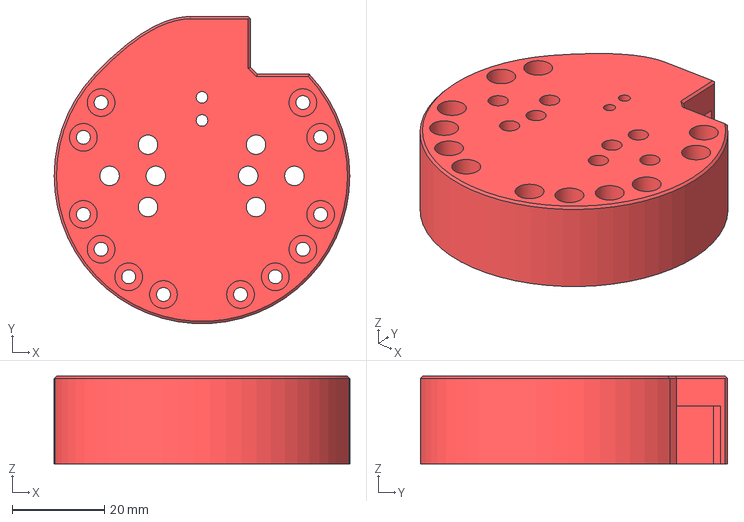
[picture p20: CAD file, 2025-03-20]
hardware/step/v2.0/HEMY2 - Output DC base.step
64.0 x 66.5 x 19.0 mm

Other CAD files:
hardware/step/v2.0/HEMY2 - I3D - GPS cover.step
hardware/step/v2.0/HEMY2 - Lateral B.step
hardware/step/v2.0/HEMY2 - I3D - Antenna Support.step
hardware/step/v2.0/HEMY2 - Bottom plate.step
hardware/step/v1.0/HEMY Base/1 - Base tripod - Base tripod.step
hardware/step/v1.0/HEMY Base/2-3-4 - Base Az - Base Az.step
hardware/step/v1.0/HEMY Base/2-3-4 - Base Az - Lateral L.step
hardware/step/v1.0/HEMY Base/2-3-4 - Base Az - Lateral R.step
hardware/step/v1.0/HEMY Base/5 - Rotation Alt - Rotation Alt.step
hardware/step/v1.0/HEMY Base/6 - Base Az Hold - Az Hold.step
hardware/step/v1.0/HEMY Base/7 - Setting Alt - Setting Alt.step
hardware/step/v1.0/HEMY Base/8 - Barrel 60mm - Barell 60mm.step
hardware/step/v1.0/HEMY Mount/01 - Main plate - Main plate.step
hardware/step/v1.0/HEMY Mount/02 - R plate - R plate.step
hardware/step/v1.0/HEMY Mount/03 - L plate - L plate.step
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

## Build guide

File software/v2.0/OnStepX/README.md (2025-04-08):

OnStepX Telescope Controller
===========================

# What is OnStepX?
OnStepX is the advanced version of the OnStep computerized telescope controller with support for interfacing with/controlling a variety of motor drivers (and so motors) including Step/Dir, ODrive, and Servo (a combination of encoder and DC motor or Stepper motor) types.

It supports:
* Telescope Mount control (Alt/Azm and Equatorial GEM/Fork.)  Optional support for Eq mounts with Tangent Arm Declination.  Usually the Goto capability is enabled, but that's optional as well for those who just want basic mount control.
* Telescope Rotator control (including Alt/Azm de-rotation.)
* Telescope Focuser control (up to 6 focusers so it can handle collimation as well as focusing.)
* Telescope Accessory control (combination of up to 8 dew-heaters, switches, analog PWM.)

# Features
OnStepX supports a wide variety of connection options.  Several serial
"command channels" can be utilized. One of the these is normally devoted to a USB
connection and for the other(s) choose from the following:

* Bluetooth
* ESP8266 WiFi
* Arduino M0/Ethernet Shield
* Even another USB port or RS232 serial isn't very difficult to add.

In the case of running OnStepX on an ESP32 it can provide its own Bluetooth or WiFi IP command channels without additional hardware by simply activating the feature in OnStepX.

Other software in the OnStep ecosystem include:

* an [ASCOM](http://ascom-standards.org/) driver (with IP and Serial support),
* an Android App useable over WiFi or Bluetooth equipped Phones/Tablets,
* a "built-in" website (on the Ethernet and/or WiFi device),
* a full planetarium program that controls all features ([Sky Planetarium](http://stellarjourney.com/index.php?r=site/software_sky)).

OnStep is compatible with the LX200 protocol. This means it can be controlled
from other planetarium software, like: Sky Safari, CdC (even without ASCOM),
Stellarium, etc.

There are also [INDI](http://www.indilib.org/about.html) drivers so it can be used from Linux, with CdC or KStars.

# Documentation
Detailed documentation, including the full set of features, detailed designs for
PCBs, instructions on how to build a controller, how to configure the firmware
for your particular mount, can all be found the [OnStep Group Wiki](https://groups.io/g/onstep/wiki/home).

# Change Log
All the changes are tracking in git, and a detailed list can be accessed using the
following git command:
 
git log --date=short --pretty=format:"%h %ad %<(20)%an %<(150,trunc)%s"

# Support
Questions and discussion should be on the mailing list (also accessible via the
web) at the [OnStep Group](https://groups.io/g/onstep/).

# License
OnStep is open source free software, licensed under the GPL.

See [LICENSE.txt](./LICENSE.txt) file.

# Author
[Howard Dutton](http://www.stellarjourney.com)

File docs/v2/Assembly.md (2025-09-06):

# ⚠️ WORK IN PROGRESS – Assembly Guide in Progress!

> **This assembly guide is still being written and improved.**
>
> Some steps may be missing, incomplete, or updated soon.
>
> If you're building HEMY, please read carefully, share feedback, and
> check the [Discussions](https://github.com/polvinc/HEMY/discussions) tab for help and updates.

___

# 🛠️ HEMY v2 Assembly Guide

This document walks you through the mechanical assembly of the HEMY v2 equatorial mount. Each section includes required parts, instructions, and suggested tips.

___
## Overall parts view 

The different parts the will be used in the current manual are presented here grouped by assembly groups. (E.g.: for the screw)
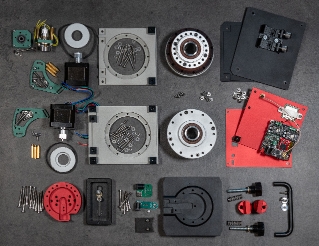
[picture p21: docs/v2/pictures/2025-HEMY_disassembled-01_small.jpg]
Overall presentation

[Full size image](./pictures/2025-HEMY_disassembled-01.jpg)

Above all, don't hesitate to open the [onshape 3D project](https://cad.onshape.com/documents/5bb7abe94ccc1dfccd880b05/w/c4dcfbc560d188dfaca97350/e/5198383ed1b9d7f502f35102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) in parallel, so that you can observe the subtleties of assembly, the details of assembly, and the sub-assemblies.

___

## Axis Assembly (common part)

### 🔧 Step 1: Harmonic Reducer Pulley Installation

<div style="flex: 1; max-width: 200px;">
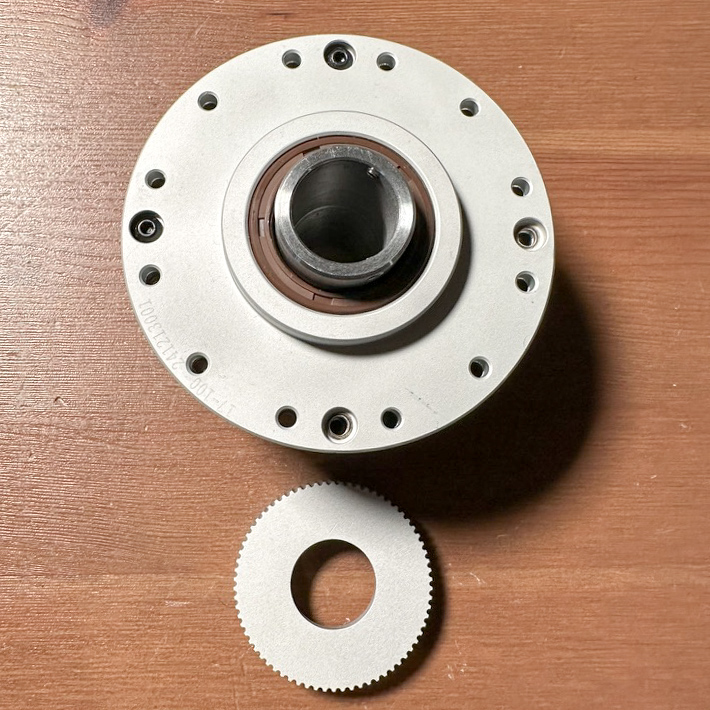
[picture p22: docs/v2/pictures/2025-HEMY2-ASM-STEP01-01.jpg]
  
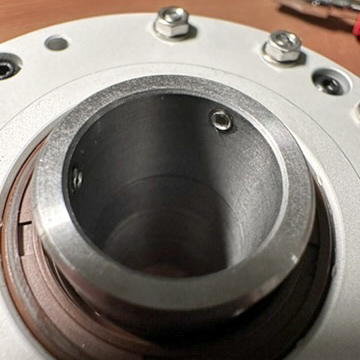
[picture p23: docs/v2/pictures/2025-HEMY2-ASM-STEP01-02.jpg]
  
</div>

**Parts:**
- C06 – Harmonic Reducer ZXK17-100 (x2)  
- A12 – Main Pulley (70T) (x2)
- S07 - Cone point hex socket set M3x3 (x3)
  
**Instructions:**  
- Foreach Pulley (70T) and Harmonic Reducer
   - Ensure correct orientation of the screws — refer to the 3D model if needed.
      - Replace cone point hex socket (original pressure screws shipped with the reducer) by shorter ones and change their orientation to push to the outside.
   - Attach the 70-tooth main pulley (A12) to one of the harmonic reducers (C06).  

Note: the original pressure screws shipped with the reducer have been replaced with shorter ones._

Note: You need the T01 tool (Allen Key).

___

## RA Axis Assembly

### 🔧 Step 2: Mount Reducer to Main Frame

<div style="flex: 1; max-width: 200px;">
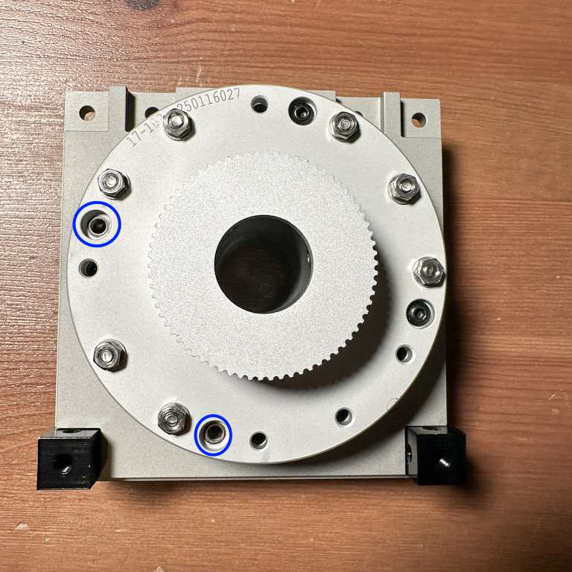
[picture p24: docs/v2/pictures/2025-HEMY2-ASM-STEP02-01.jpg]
  
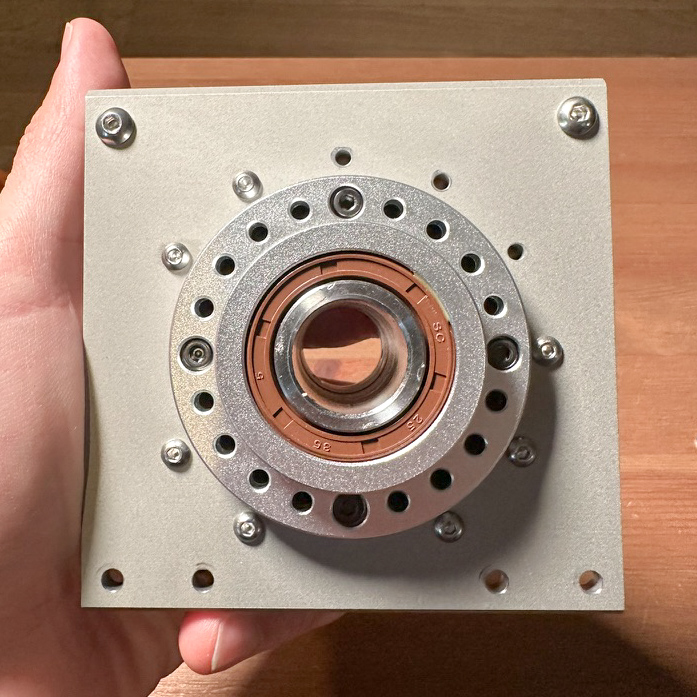
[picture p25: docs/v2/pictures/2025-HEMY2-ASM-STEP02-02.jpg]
  
</div>

**Parts:**  
- A01 – Main Frame A (x1)  
- C10 – Square Corner Screw M4 (x2)  
- S19 – M4x8 Screws (x2)  
- S06 – M3x30 Screws (x7)  
- S02 – M3 Washers (x7)  
- S10 – M3 Nuts (x7)

**Instructions:**  
Fix two M4 square corner cubes (C10) onto Main Frame A (A01) using one M4x8 screw each. Then install the reducer (C06) using M3x30 screws with washers and nuts. 

- Double-check the reducer's orientation by identifying its screws and orienting them as in the picture.

- Double-check the reducer's alignment.

Due to the necessity to ensure that the reducer fits into the space, a little margin has been taken. Therefore, it is important to verify that there is as much space between the reducer and the main plate on each side.
  
> Tip: a 3D-printed centering tool can be helpful for perfect alignment. (To be build.)
> 
> Tip: put the same folded paper sheet on four sides of the reducer.

- Once the reducer is in place, remove the two screws indicated in blue on the photo (for later brake mount).

___

### 🔧 Step 3: Brake Sub-Assembly

<div style="flex: 1; max-width: 200px;">
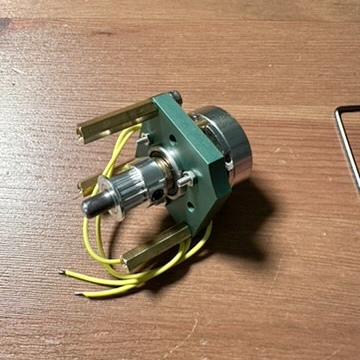
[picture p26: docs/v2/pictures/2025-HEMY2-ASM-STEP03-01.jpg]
  
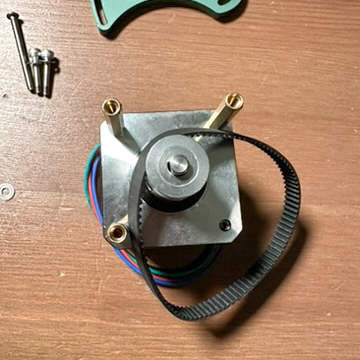
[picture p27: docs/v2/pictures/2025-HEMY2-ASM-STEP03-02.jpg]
  
</div>

**Parts:**
- C08 - Shaft 5x45mm-Grind Flat
- A07 – Brake Support (x2)
- C15 – Brake (SWB-003) (x1)  
- C05 - Bearing 625ZZ (x2)
- S03 – Washer M5 (x2)  
- C01 – Pulley GT2 16T (x1)

- C12 – Spacer M3x19mm FF (x3)  
- S05 – M3x10 Screws (x6)
  
- S04 – M2x10 Screws (x3)  
- S01 – Washer and nuts M2 (x3)
- C04 - GT2 Belt – 200 mm

**Instructions:**

#### 🔧 Step 3.1: shaft sub assembly :
1. The grinding of the shaft is insufficient. It is necessary to complete this grinding to fit into the brake connection piece. Perform grinding over the full length of the shaft.
2. On One Break support assemble the spacer with M3 screws.
3. Then from this support, assemble from left to right on the shaft (note: The belt shall be inserted to go around the pulley) :
   1. Break Support
   2. Bearing
   3. Washer M5
   4. Pulley GT2 (Tighten it with the pulley screw).
   5. Washer
   6. Bearing
   7. Break support
4. Screw the last Break support to the Spacer.
5. Unscrew the pulley screw so that the end of the bar does not protrude beyond the edge of the brake support when the pulley is resting on the brake support.
6. Insert the brake connection piece on the other side of the shaft so that it is as close as possible to the support without touching it (1mm margin).

The result should be consistent to the following (save for the belt that shall have been inserted and cannot be seen here) :

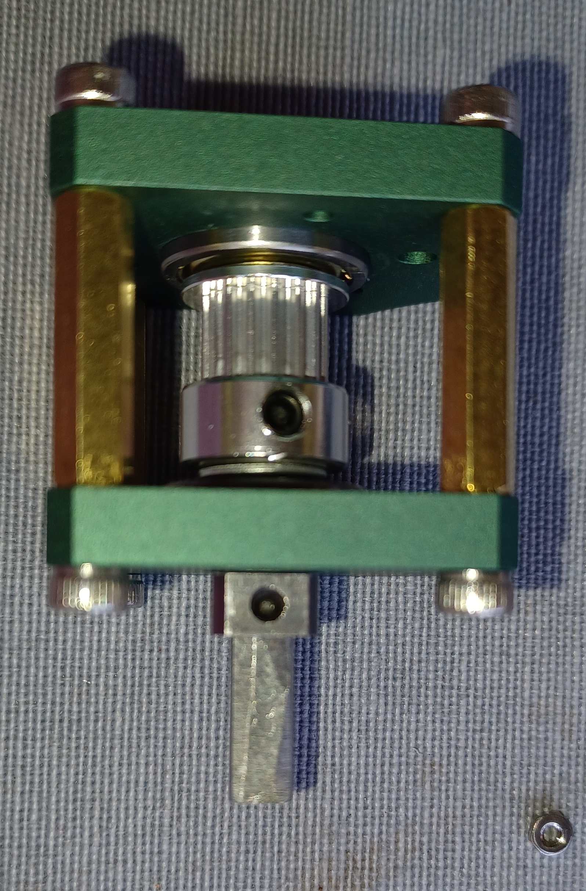
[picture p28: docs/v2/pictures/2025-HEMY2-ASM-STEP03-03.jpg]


#### 🔧 Step 3.2: Break preparation :
The connecting screws of the break shall be replaced with longer M2 screws.

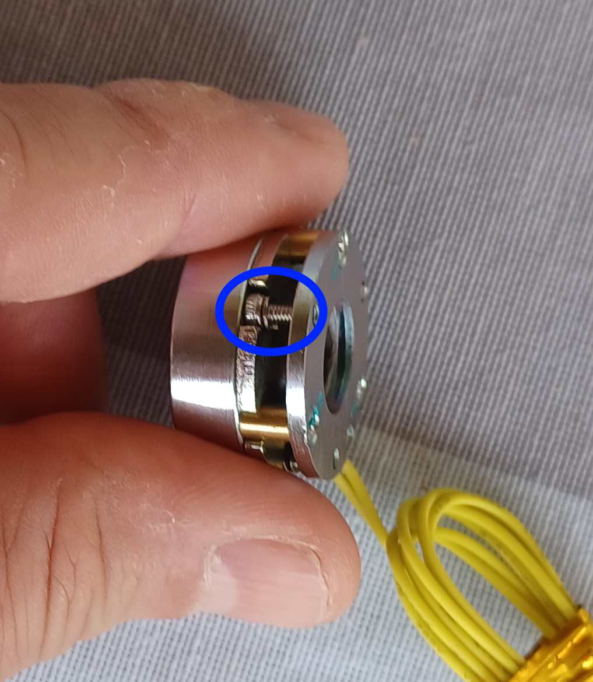
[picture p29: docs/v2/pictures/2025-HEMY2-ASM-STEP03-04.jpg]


For this you need to unscrew the following screws.

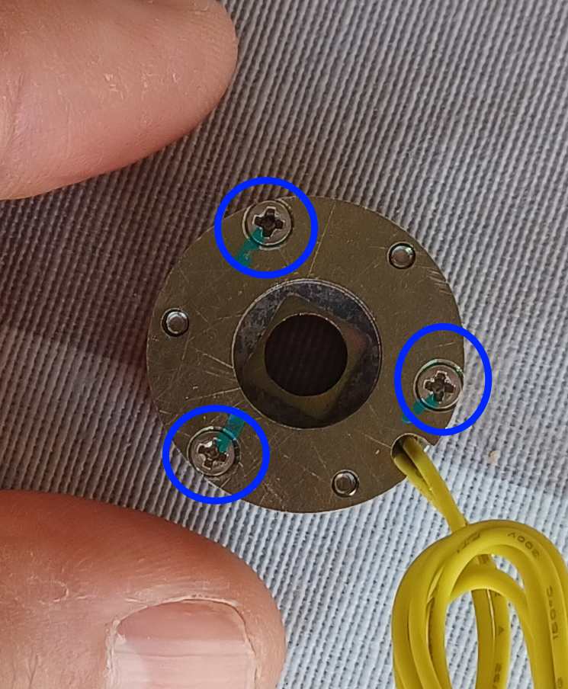
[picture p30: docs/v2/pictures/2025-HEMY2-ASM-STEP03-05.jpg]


As those screws are tighted strongly, you will need a strong screw driver. You shall be carefull whhile unscrewing, to avoid the internal springs to get out from coming out of their housing.

Replace the screws with the M2 screws.

#### 🔧 Step 3.3: Final Results :

Results should look like :

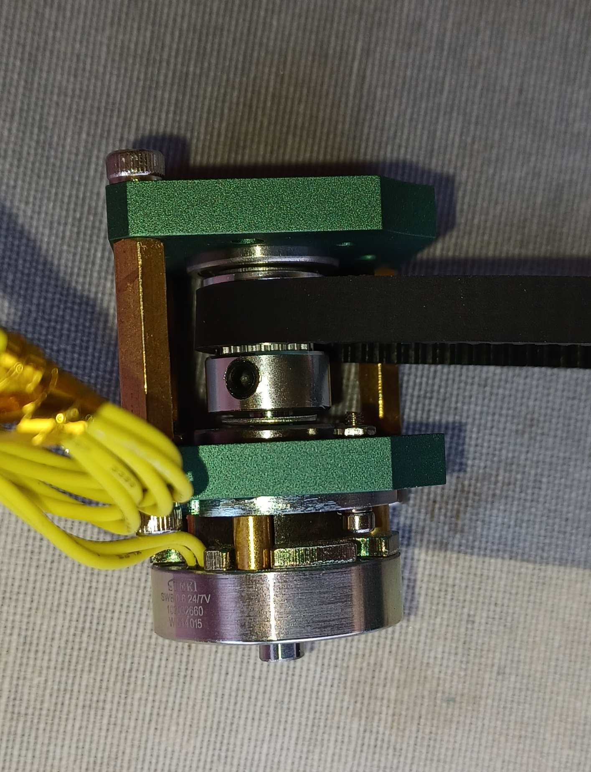
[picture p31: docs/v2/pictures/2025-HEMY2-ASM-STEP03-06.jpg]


Mount the brake (C15) to its upper support plate (A07) using three M3x19mm spacers and M3x10 screws. Use M2 washers and screws where needed for the electrical interface. Install the GT2 16T pulley (C01) onto the brake shaft.

___

### 🔧 Step 4: RA Assembly & Belt Tensioning

<div style="display: flex; margin-bottom: 5px;">
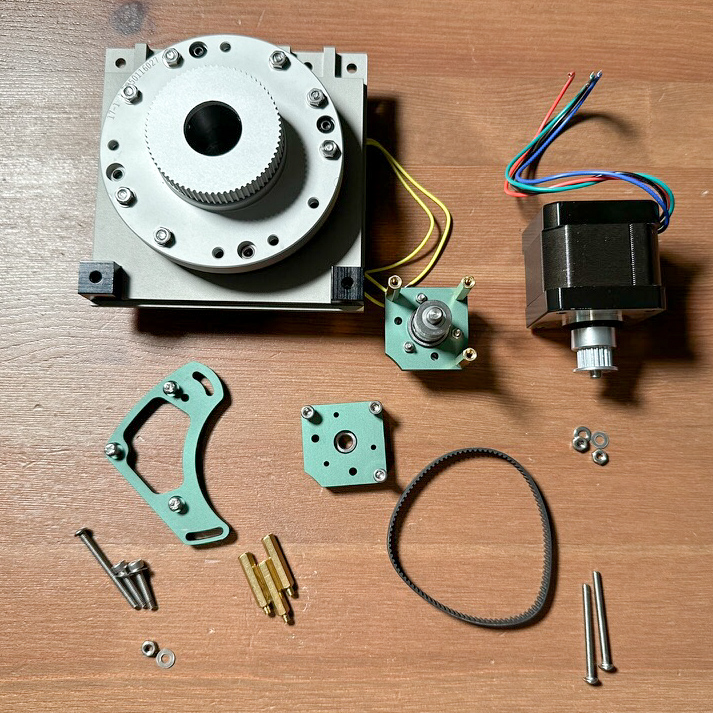
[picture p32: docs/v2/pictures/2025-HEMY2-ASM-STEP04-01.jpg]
  
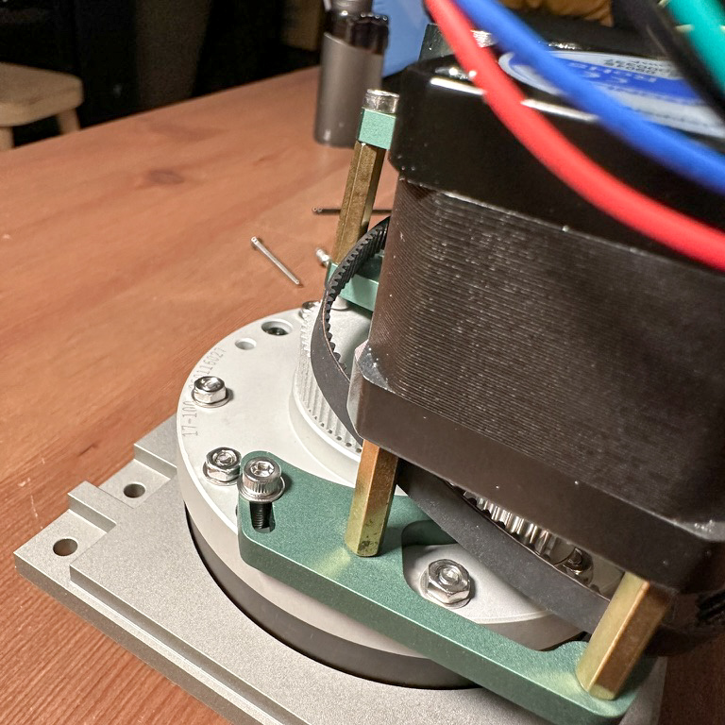
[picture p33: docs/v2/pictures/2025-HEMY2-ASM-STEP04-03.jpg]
  
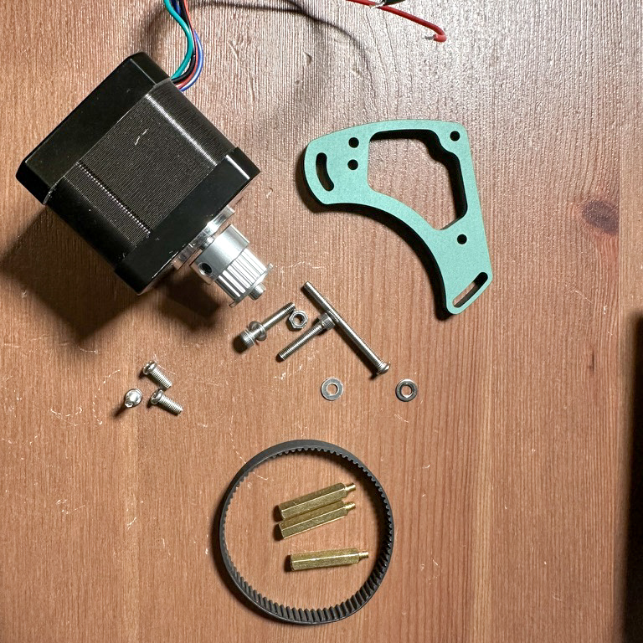
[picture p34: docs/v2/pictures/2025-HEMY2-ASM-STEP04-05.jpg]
  
</div>
<div style="display: flex; margin-bottom: 5px;">
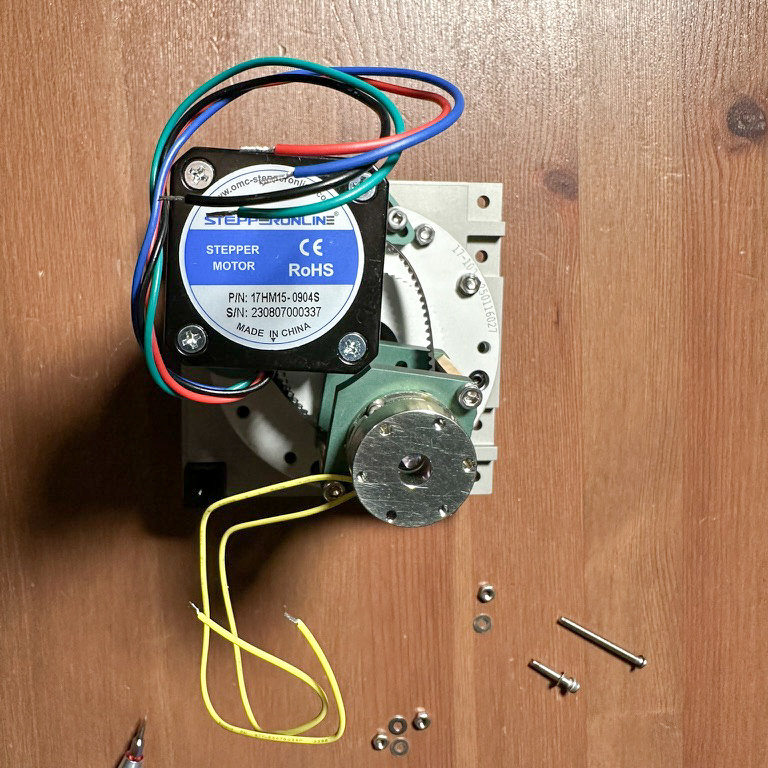
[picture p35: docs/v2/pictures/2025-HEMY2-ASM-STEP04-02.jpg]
  
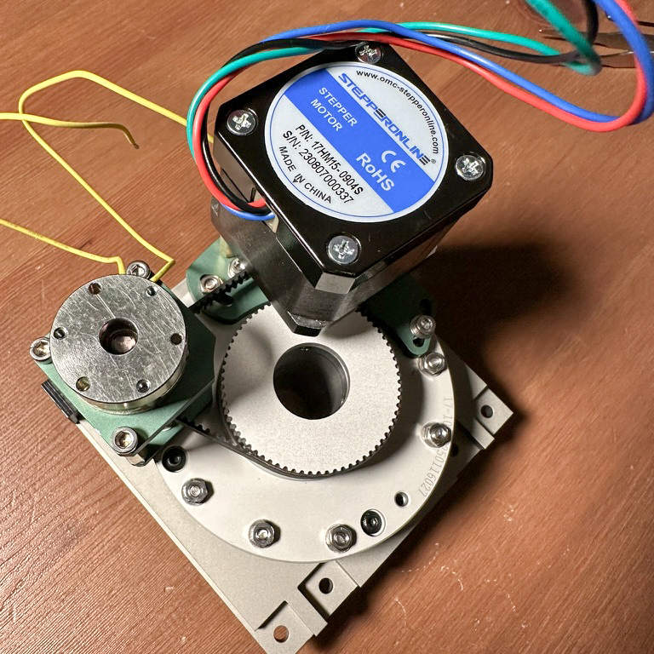
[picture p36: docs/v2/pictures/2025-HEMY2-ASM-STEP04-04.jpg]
  
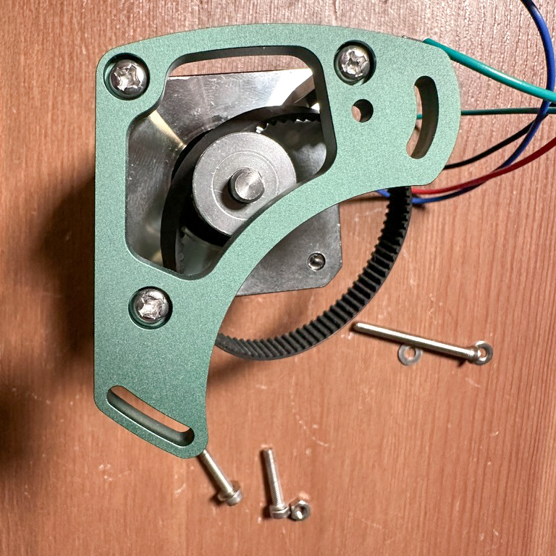
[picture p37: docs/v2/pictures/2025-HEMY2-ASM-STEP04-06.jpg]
  
</div>

<div style="display: flex; margin-bottom: 5px;">
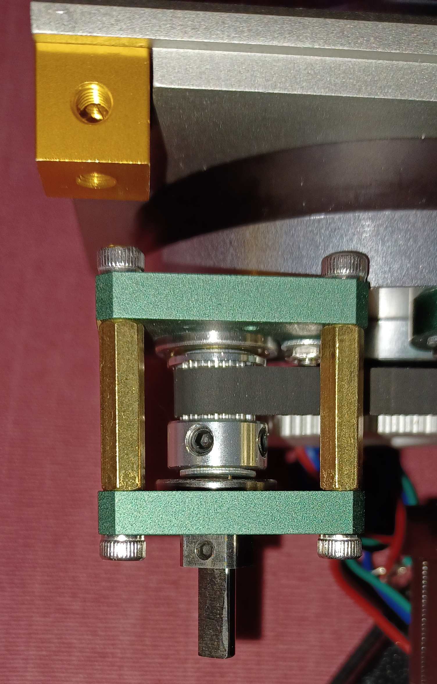
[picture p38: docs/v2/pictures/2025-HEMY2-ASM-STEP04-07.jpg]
  
</div>

**Parts:**
- A07 – Brake Support (x1)  

- A08 – Motor Support (x1)  
- C04 – GT2 Belt 200mm (x1)  
- C02 – Pulley GT2 20T (x1)  
- C07 – NEMA17 Motor (x1)  
- C11 – Spacer M3x21mm FM (x3)  
- S15 – M3x35 Screws (x3)  
- S06 – M3x16 Screws (x2)  
- S10 – M3 Nuts (x4)

**Instructions:**  
This is the most delicate step — take your time!

1. Prepare the NEMA17 motor (C07) with the GT2 20T pulley (C02) and three M3x21mm spacers (C11).
2. Position the belt (C04) around the brake pulley (C01).
3. Close the assembly with the lower brake support (A07).
4. Place the motor support (A08) onto the motor.
5. Lightly secure the motor to the reducer using one screw (indicated blue in the photo) — don't tighten fully yet.
6. Mount the brake onto the reducer using two M3x35 screws and nuts.
7. Insert the final two screws (red in photo) and adjust belt tension carefully.

🎉 Congratulations! The RA axis sub-assembly is now complete — the most challenging part is done!

___

## DEC Axis Assembly

### 🔧 Step 5: Main Pulley Installation

<div style="flex: 1; max-width: 200px;">
  
  
</div>

**Parts:**
- C06 – Harmonic Reducer ZXK17-100 (x1)  
- A12 – Main Pulley (70T) (x1)
- S07 - Cone point hex socket set M3x3 (x3)

**Instructions:**  
As in Step 1, attach the 70T main pulley to the second harmonic reducer. Ensure the correct screw orientation — consult the 3D model. Use the shorter replacement pressure screws provided.

___

### 🔧 Step 6: Attach Cubes to Main Frame B

<div style="flex: 1; max-width: 200px;">
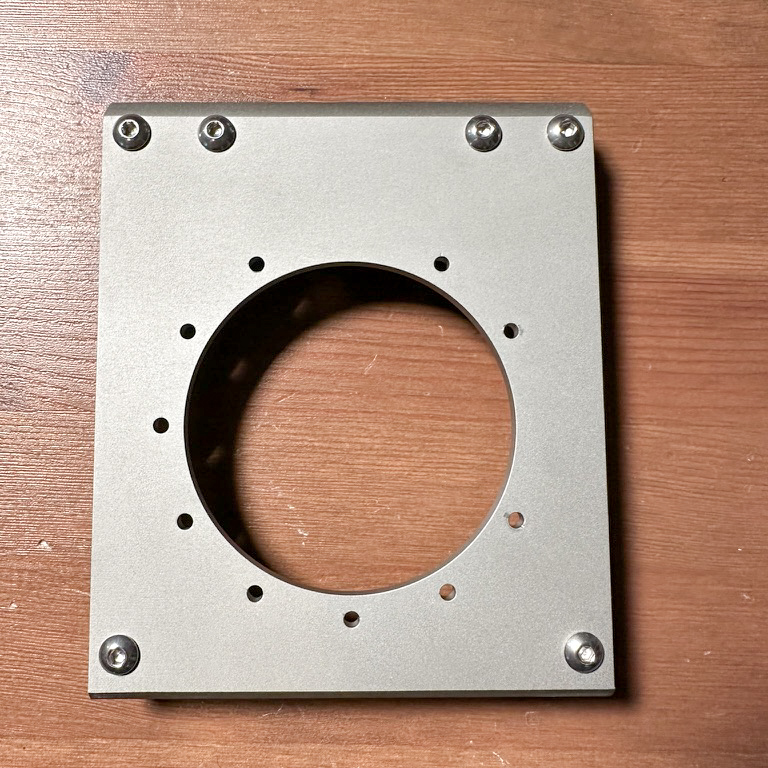
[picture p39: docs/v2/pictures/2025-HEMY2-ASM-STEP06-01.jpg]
  
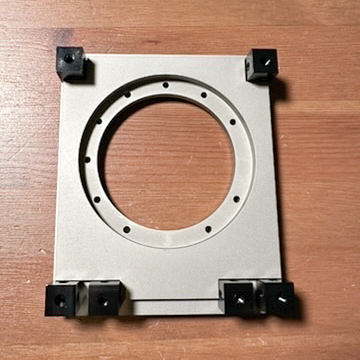
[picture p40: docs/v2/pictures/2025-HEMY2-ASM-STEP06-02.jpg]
  
</div>

**Parts:**
- A02 – Main Frame B (x1)  
- C10 – Square Corner Screw M4 (x6)  
- S19 – M4x10 Screws (x6)

**Instructions:**  
Attach all six M4 corner cubes (C10) to the Main Frame B (A02) using M4x8 screws.

___

### 🔧 Step 7: Mount DEC Reducer

<div style="flex: 1; max-width: 200px;">
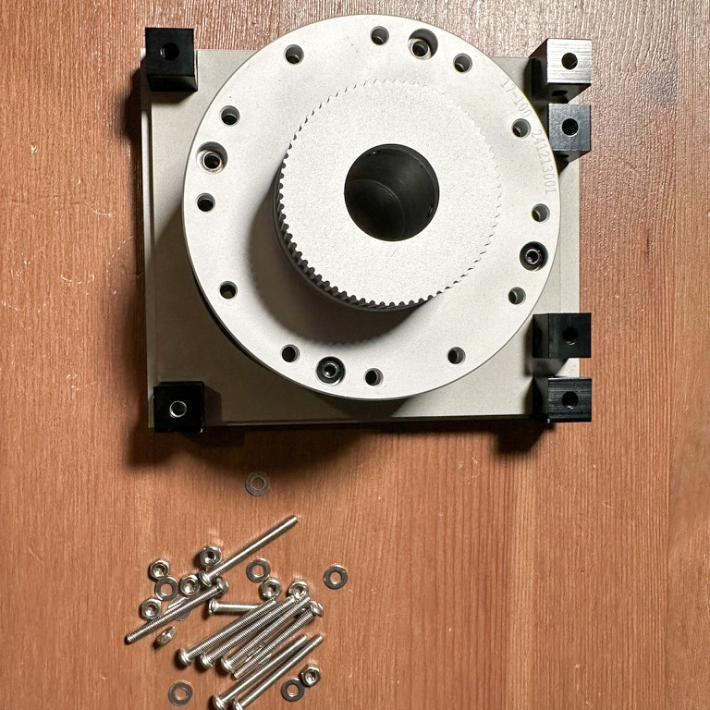
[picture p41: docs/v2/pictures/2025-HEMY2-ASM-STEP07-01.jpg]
  
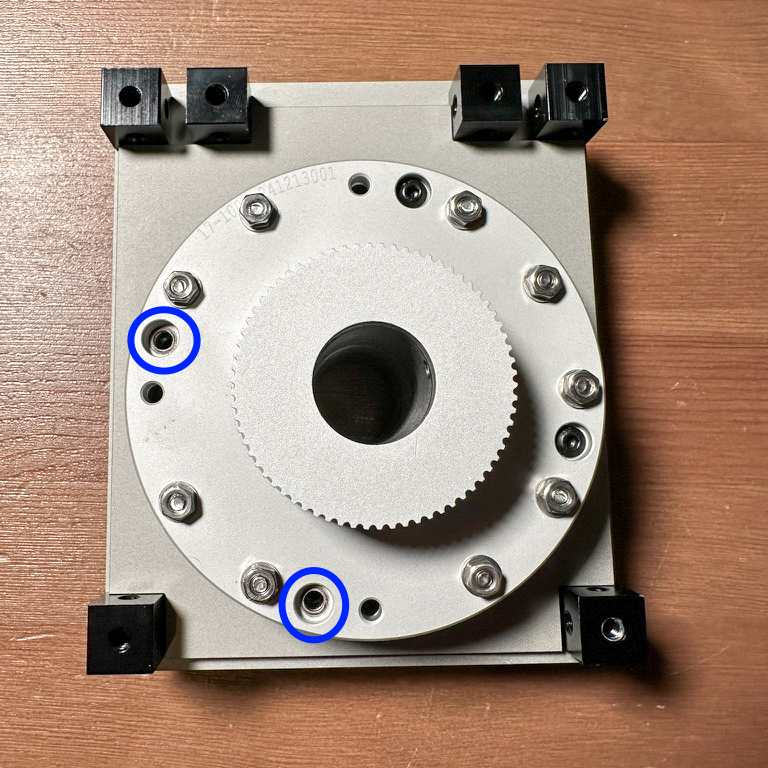
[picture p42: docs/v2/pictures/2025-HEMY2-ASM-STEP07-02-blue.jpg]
  
</div>

**Parts:**
- S06 – M3x30 Screws (x9)  
- S02 – M3 Washers (x9)  
- S10 – M3 Nuts (x9)

**Instructions:**  
Center the harmonic reducer with its pulley onto Main Frame B (A02), and secure it using M3x30 screws with washers and nuts.

Make sure to properly orient the harmonic reducer in the main part, using the reducer screws as reference points. 

Note that two of these screws will be removed and replaced in a step described below with screws that will hold the motor. (See photo at the bottom left). 

Before proceeding with the extraction of these screws, ensure that the 9 connecting screws of the harmonic reducer and the main part are tightly secured.

> Tip: A 3D-printed alignment jig is helpful here as well.

Once aligned and fastened, remove the two blue-marked screws from the reducer (as shown in the photo).

___

### 🔧 Step 8: Prepare Motor Assembly

<div style="flex: 1; max-width: 200px;">
  
  
</div>

**Parts:**
- C07 – NEMA17 Motor (x1)  
- C02 – Pulley GT2 20T (x1)  
- C03 – GT2 Belt 166mm (x1)  
- C11 – Spacer M3x21mm FM (x3)
- S16 - Socket button head M3x12 (x3)

**Instructions:**  
Mount the GT2 20T pulley onto the NEMA17 motor shaft. Add the three 21mm spacers and fit the 166mm GT2 belt.

___

### 🔧 Step 9: Mount Motor to Reducer

<div style="flex: 1; max-width: 200px;">
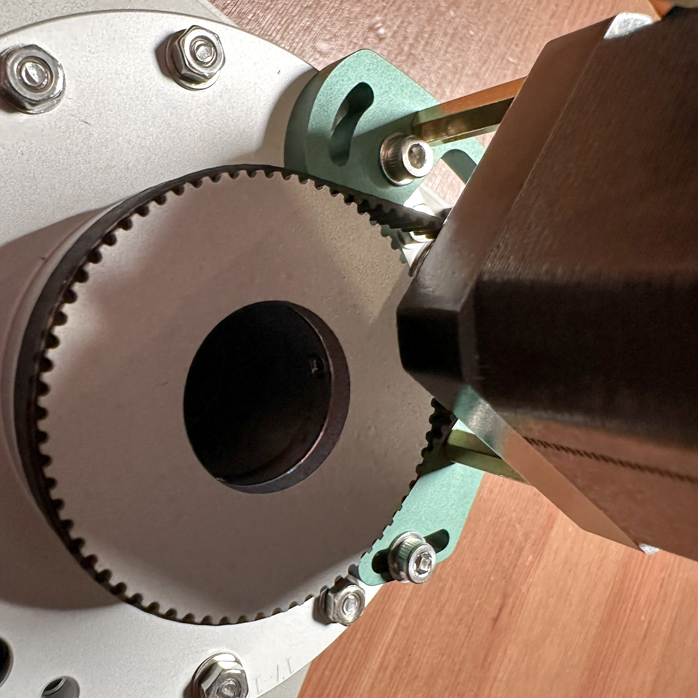
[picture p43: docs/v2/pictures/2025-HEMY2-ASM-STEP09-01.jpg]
  
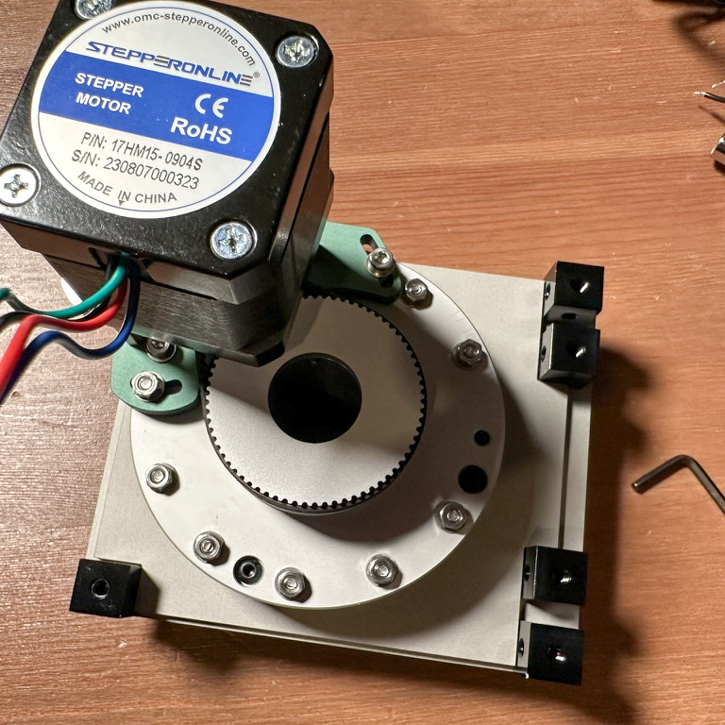
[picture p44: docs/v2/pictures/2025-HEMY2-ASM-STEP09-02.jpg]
  
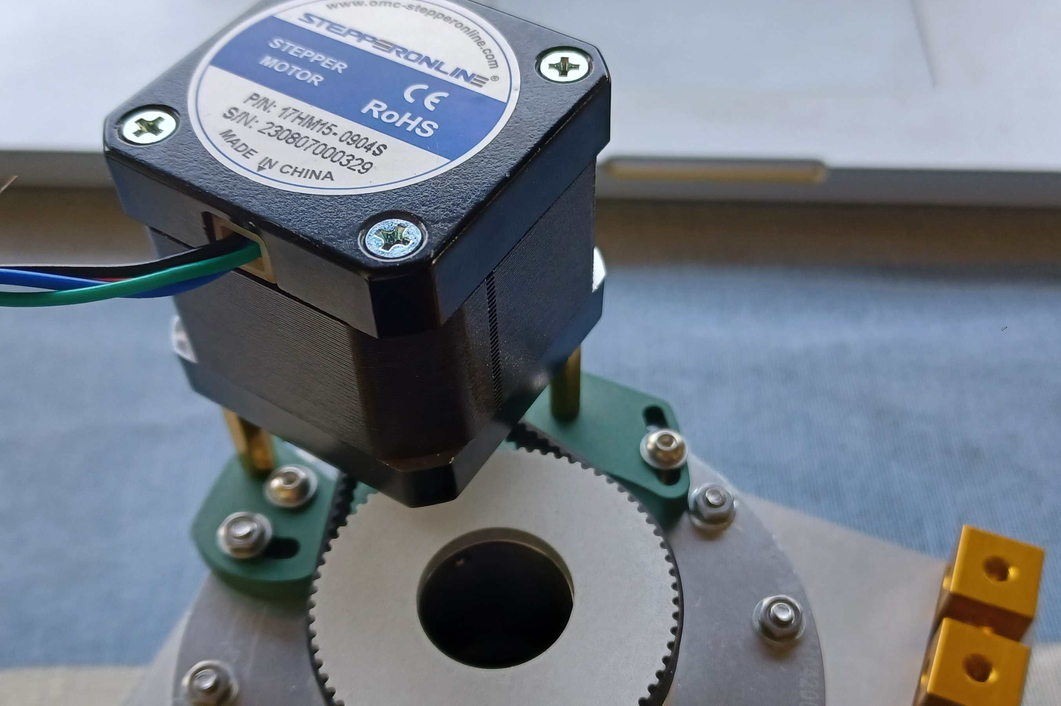
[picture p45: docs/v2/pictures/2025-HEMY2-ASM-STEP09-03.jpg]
  
</div>

**Parts:**
- S15 – M3x35 Screws (x1)  
- S02 – M3 Washers (x1)  
- S10 – M3 Nuts (x1)
- S13 – M3x16 Screws (x2)

**Instructions:**  
Position the motor assembly on the reducer. Use the M3x35 screws and M3x16 screws to fasten everything and tension the belt accordingly.

🎉 The DEC axis is now fully assembled!

___

## Axis Frame Assembly

### 🔧 Step 10: Connect RA and DEC Axes

<div style="flex: 1; max-width: 200px;">
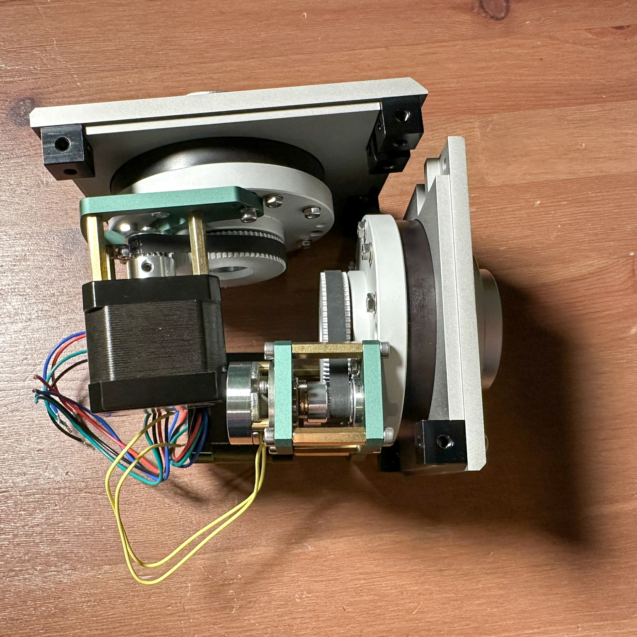
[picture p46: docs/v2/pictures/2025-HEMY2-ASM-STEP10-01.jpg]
  
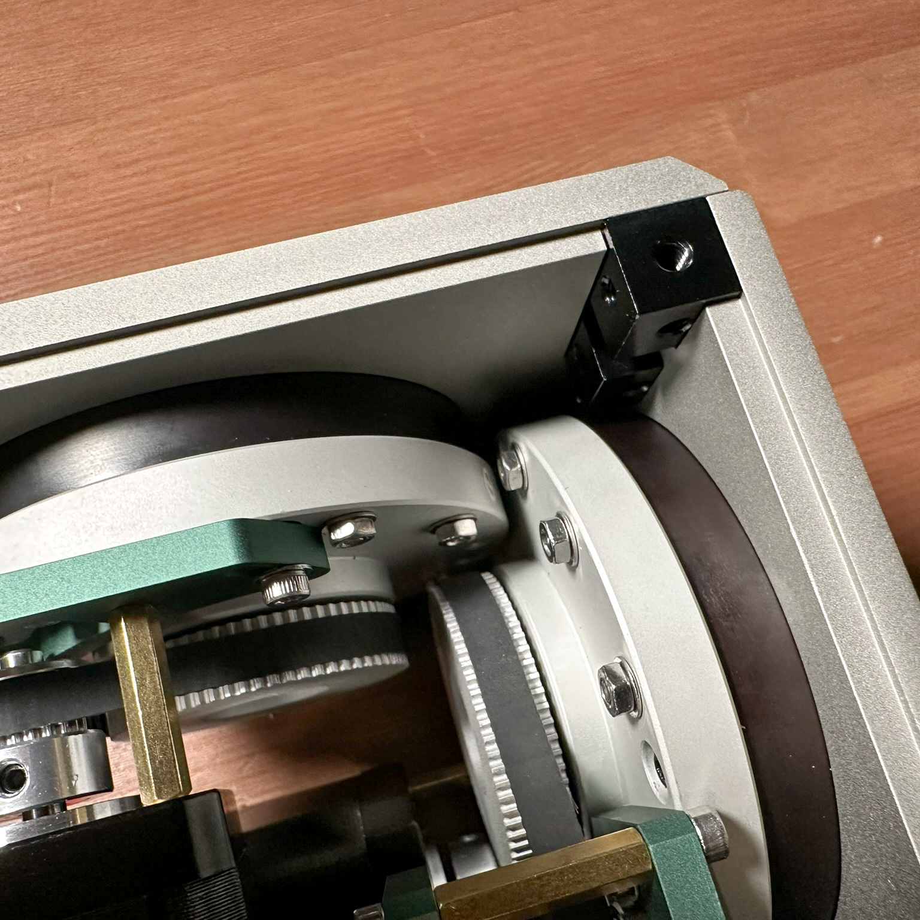
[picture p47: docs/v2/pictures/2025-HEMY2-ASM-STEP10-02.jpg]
  
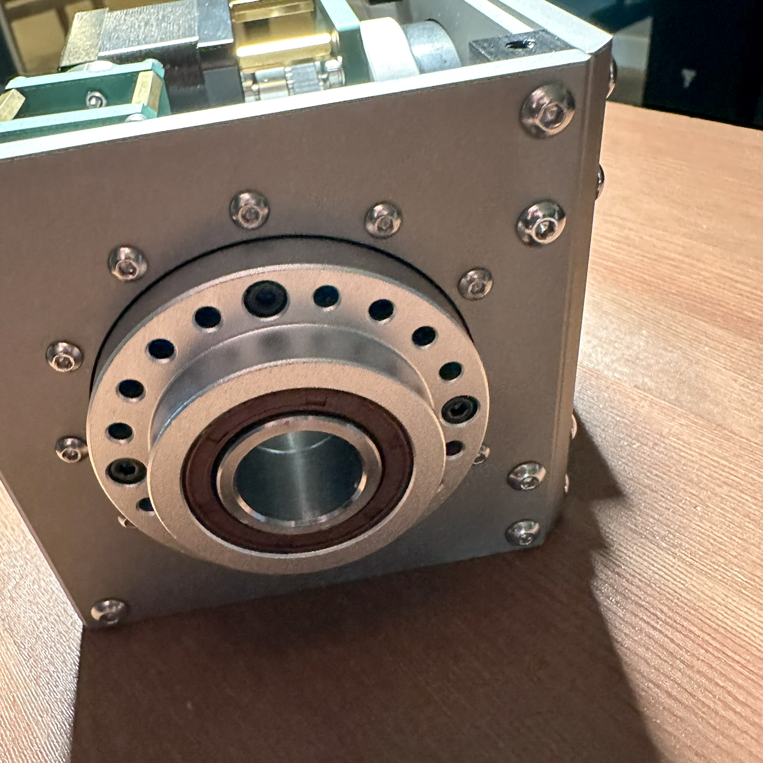
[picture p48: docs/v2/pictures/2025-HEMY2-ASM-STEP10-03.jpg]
  
</div>

**Parts:**
- A01 – Main Frame A (RA side)  
- A02 – Main Frame B (DEC side)  
- S18 – M4x10 Screws (x4 or more as needed)

**Instructions:**  
Position the RA and DEC sub-assemblies to form a right angle (90°) between the two main frame plates (A01 and A02). Align the corresponding mounting holes and loosely fasten them using M4x10 screws.  
> ⚠️ Do not fully tighten the screws yet — the final squaring and reinforcement will be done with the lateral plates in later steps.

___

## Dovetail Assembly

> ⚠️ Note: The USB and DC passthrough electronics for the dovetail are still experimental and not fully tested.

### 🔧 Step 11: Attach Electronics and Cover

<div style="flex: 1; max-width: 200px;">
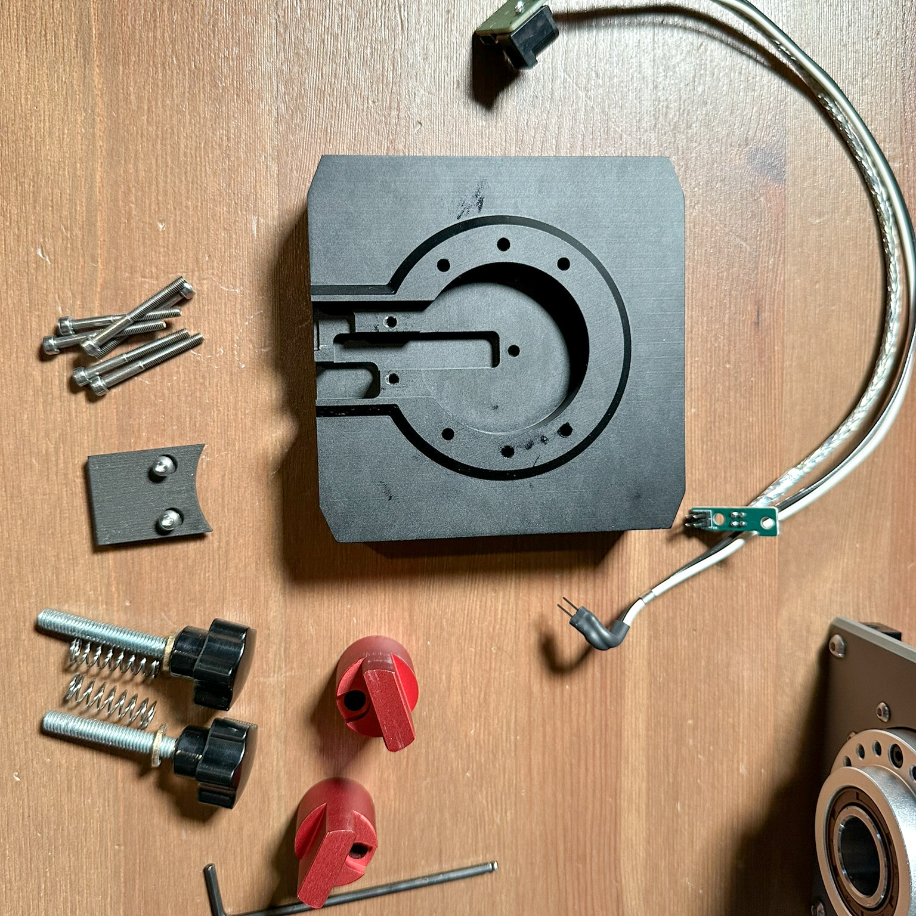
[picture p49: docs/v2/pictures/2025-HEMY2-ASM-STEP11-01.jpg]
  
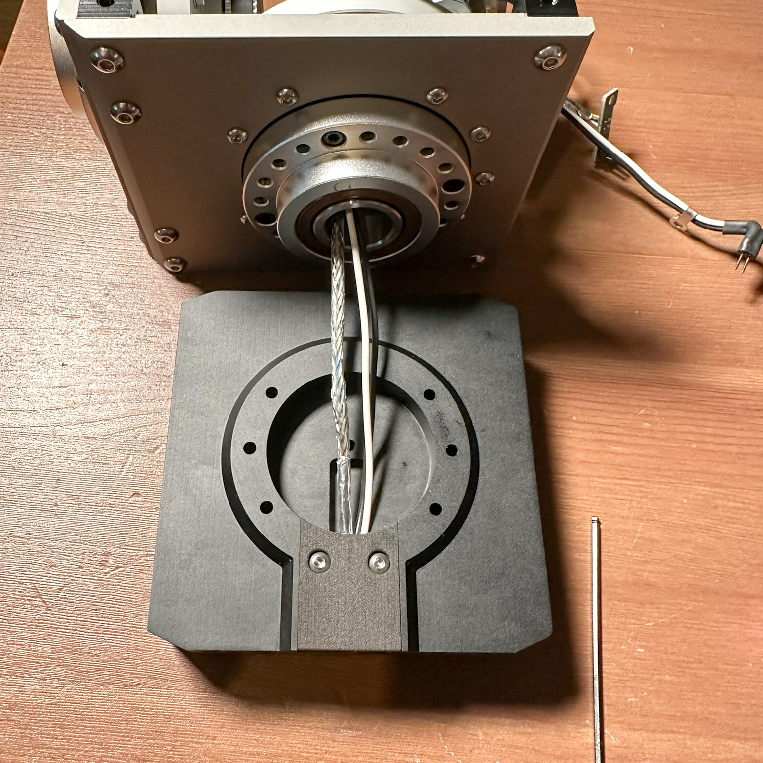
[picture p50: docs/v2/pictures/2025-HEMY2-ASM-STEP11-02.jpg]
  
</div>

**Parts:**
- B01 – Dovetail PCB Cover (x1)  
- PCB07 – Dovetail passthrough board (experimental)  
- A09 – Vixen/Losmandy Dovetail (x1)
- S18 – M4x10 Screws (x2)

**Instructions:**  
Position the passthrough PCB onto the dovetail (A09) and secure the 3D-printed cover (B01) as shown.

___

### 🔧 Step 12: Mount Dovetail on DEC Reducer

<div style="flex: 1; max-width: 200px;">
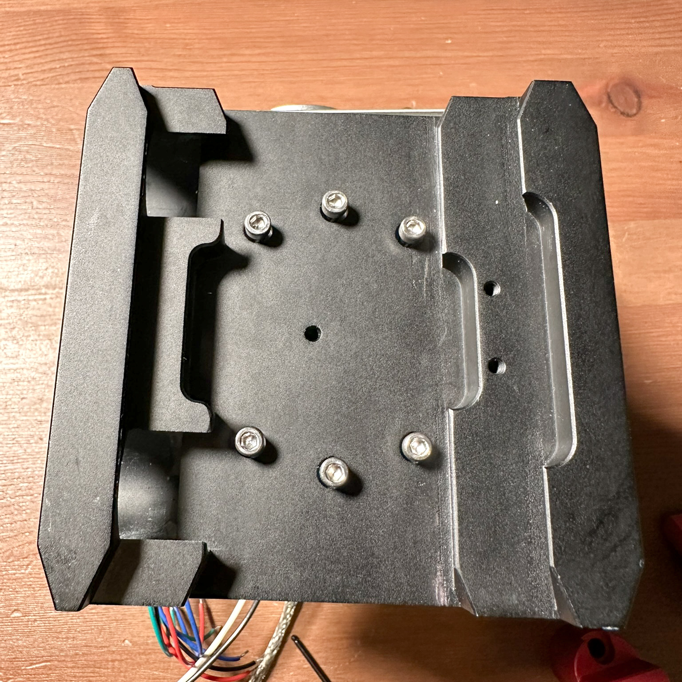
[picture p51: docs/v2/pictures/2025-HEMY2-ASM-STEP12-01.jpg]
  
</div>

**Parts:**
- S06 – M3x30 Screws (x2)

**Instructions:**  
Route the cables through the reducer’s central cutout, then secure the dovetail (A09) to the DEC reducer using M3x30 screws.

___

### 🔧 Step 13: Install Clamps

<div style="flex: 1; max-width: 200px;">
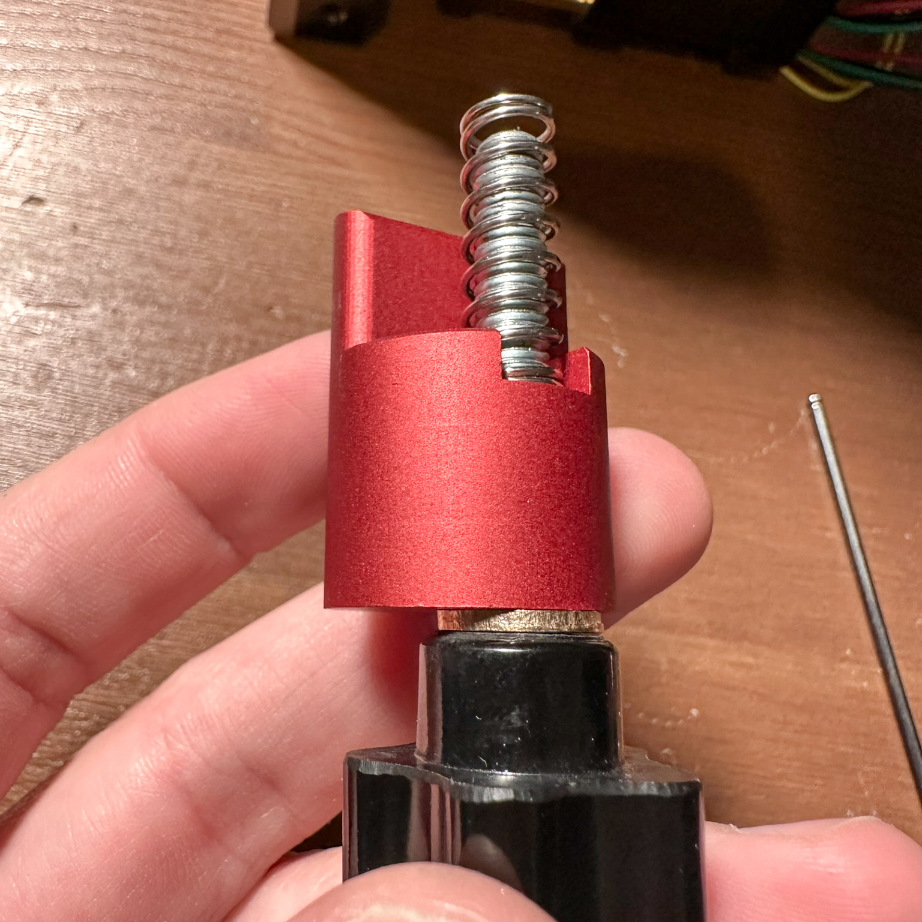
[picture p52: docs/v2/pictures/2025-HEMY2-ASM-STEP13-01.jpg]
  
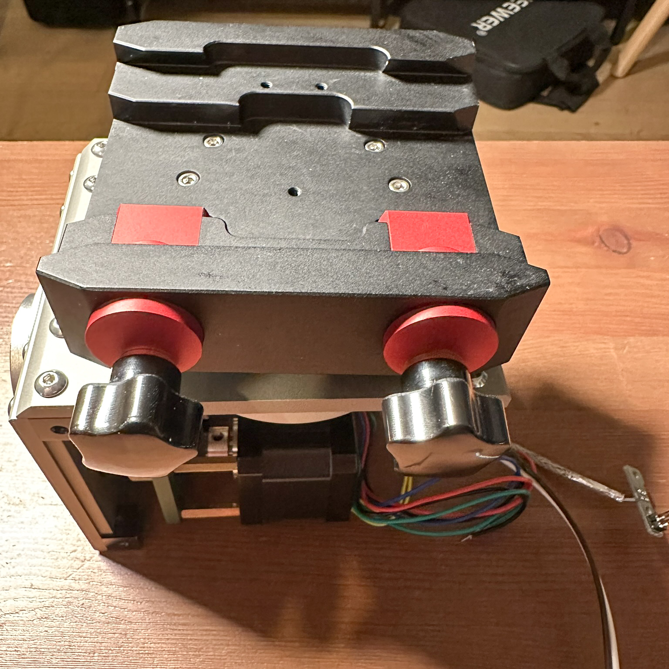
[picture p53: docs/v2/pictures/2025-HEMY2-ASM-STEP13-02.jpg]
  
</div>

**Parts:**
- A10 – RFix Dovetail Clamps (x2)  
- C20 – Button Screws M6x40 with Springs (x2)

**Instructions:**  
Insert the two clamps (A10) into the dovetail (A09), secure them using the M6x40 button screws and springs.

🎉 The dovetail interface is now installed and ready to hold your telescope!

___

## Lateral Plates and Electronics

### 🔧 Step 14: Mount Lateral Plate B and Secure Frame

<div style="flex: 1; max-width: 200px;">
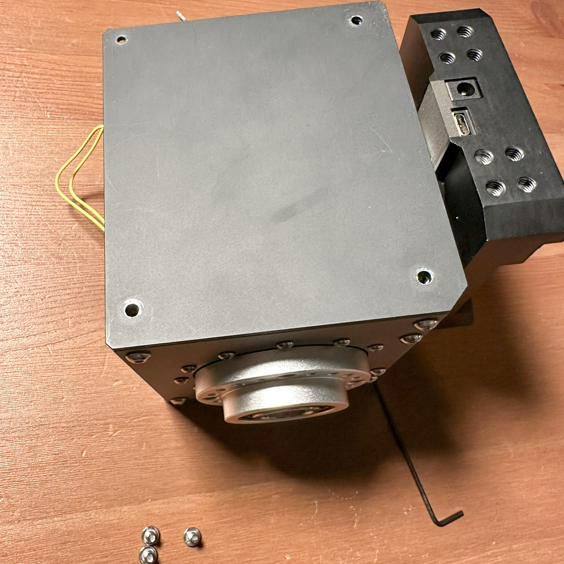
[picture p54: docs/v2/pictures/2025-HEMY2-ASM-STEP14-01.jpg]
  
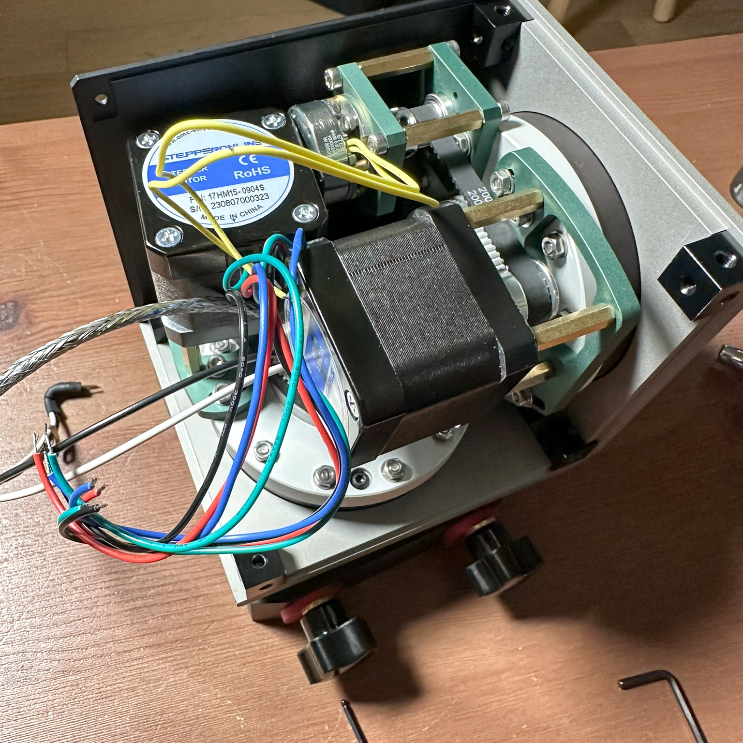
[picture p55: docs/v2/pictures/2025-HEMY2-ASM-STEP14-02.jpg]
  
</div>

**Parts:**
- A04 – Lateral Plate B (x1)  
- S19 – M4x8 Screws (as needed)

**Instructions:**  
Attach the lateral plate (A04) to the RA/DEC frame to complete the squared bracket. Once aligned, tighten all previously loose screws to secure the overall structure.

___

### 🔧 Step 15: Install Top Electronics

<div style="display: flex; margin-bottom: 5px;">
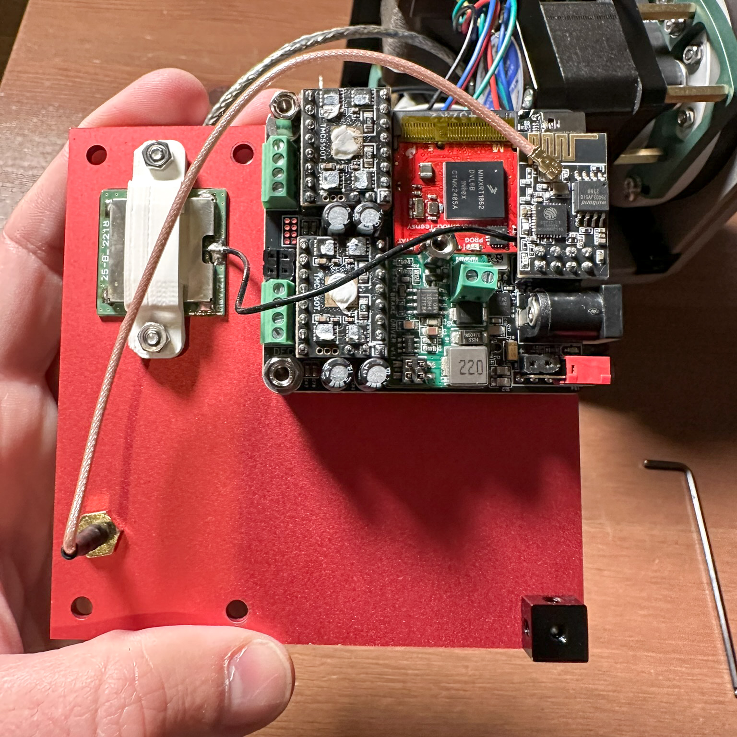
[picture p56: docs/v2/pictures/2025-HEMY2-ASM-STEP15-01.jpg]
  
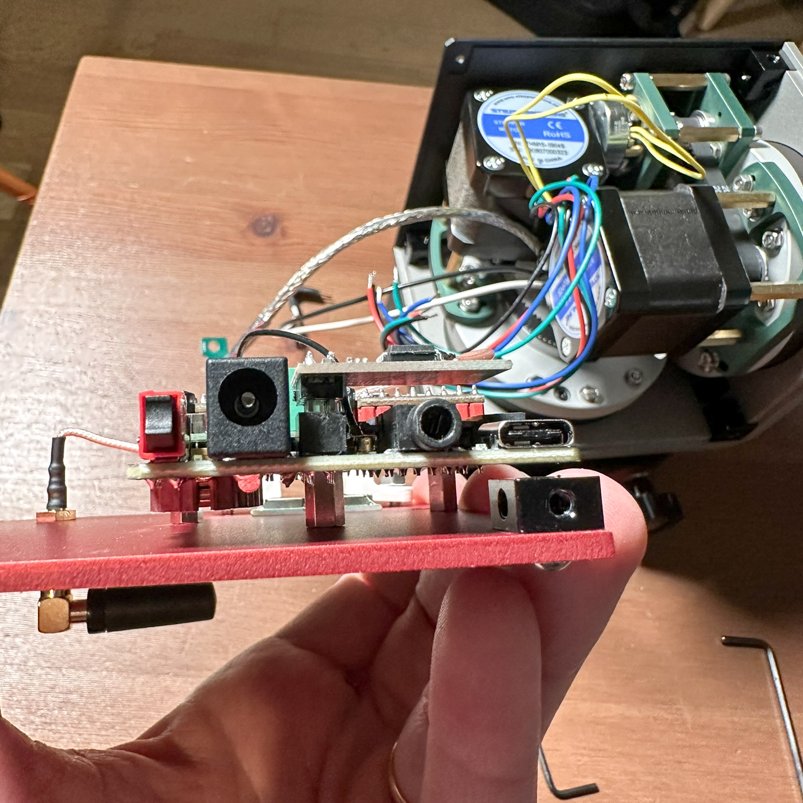
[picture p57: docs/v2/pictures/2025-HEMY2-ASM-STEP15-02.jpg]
  
</div>

<div style="display: flex;">
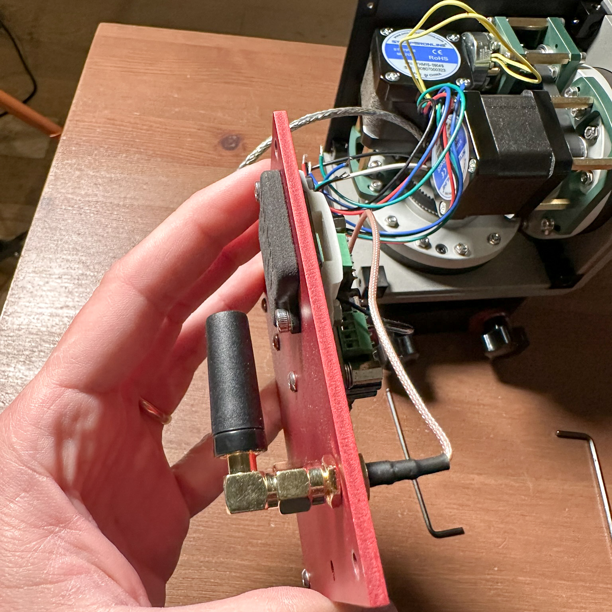
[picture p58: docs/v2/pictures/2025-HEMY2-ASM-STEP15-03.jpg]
  
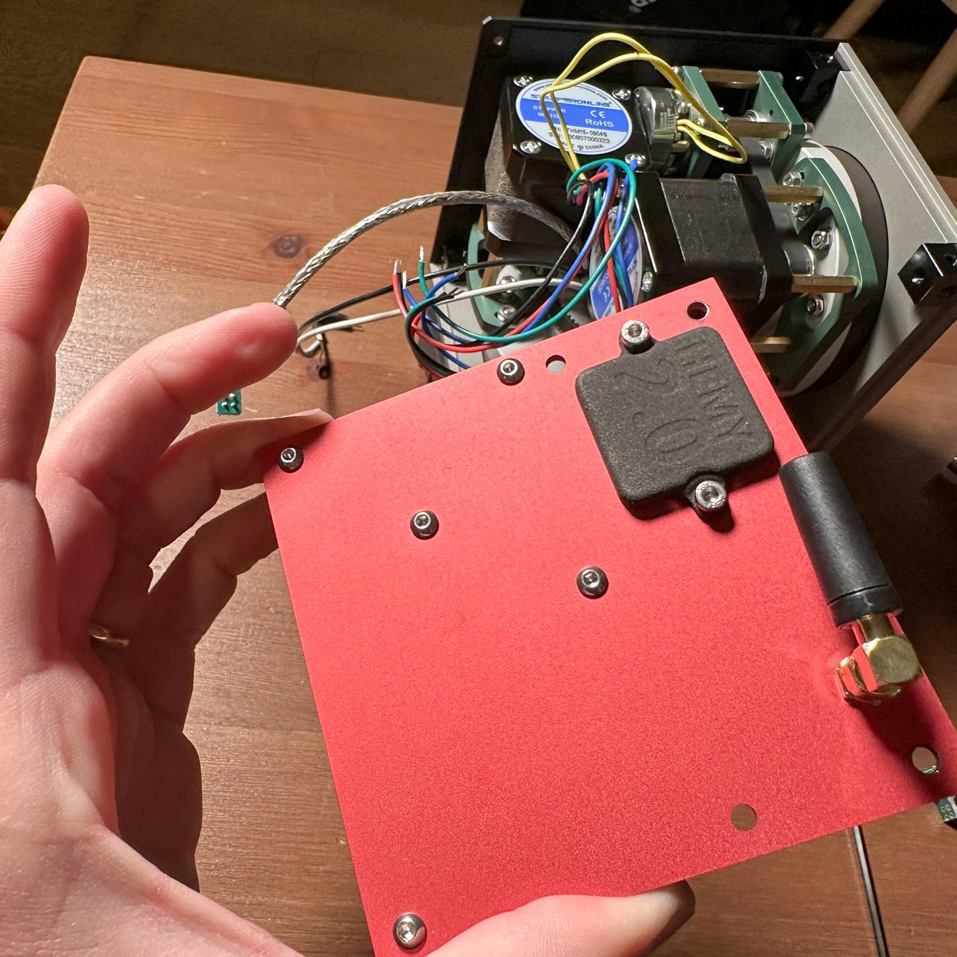
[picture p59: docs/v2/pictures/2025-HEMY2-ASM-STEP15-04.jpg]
  
</div>

**Parts:**
- All PCBs (assembled, see `pcb_assembly.md`)  
- C13 – Spacer M3x8mm FF (x3)  
- Handle, GPS antenna, GPS cover

**Instructions:**  
Install two M3 corner cubes on the top plate. Mount the main assembled PCB (including brake driver, TMC5160s, and Teensy) on the top plate using the M3x8 spacers. Install the handle and antennas (Wi-Fi and GPS), and place the GPS antenna cover (B02).
Make sure all cables are connected and routed cleanly.

___

### 🔧 Step 16: Final Assembly of Top/Bottom/Lateral Plates

<div style="display: flex; margin-bottom: 5px;">
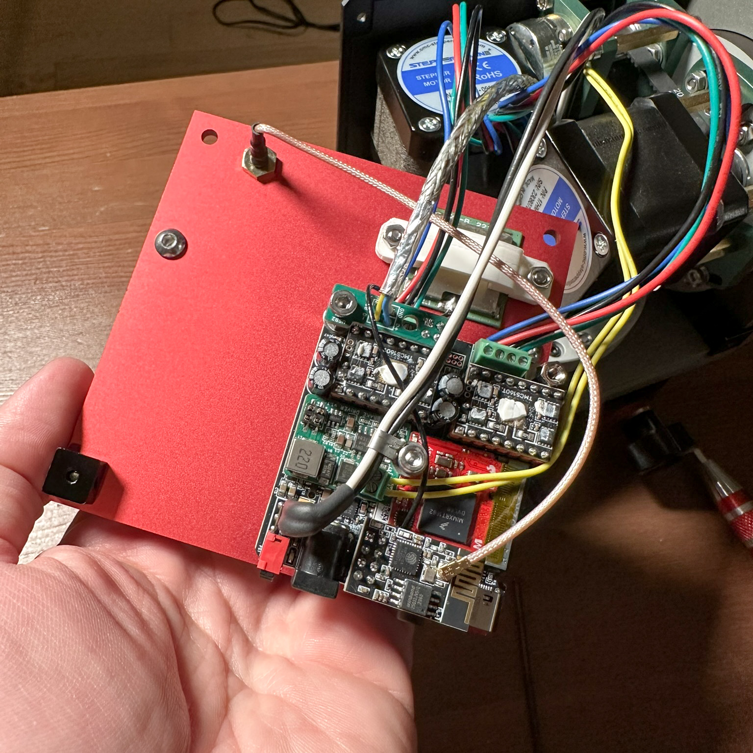
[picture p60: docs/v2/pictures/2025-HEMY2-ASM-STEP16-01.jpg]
  
  
</div>

<div style="display: flex;">
  
  
</div>

**Parts:**
- A05 – Top Plate  
- A06 – Bottom Plate  
- A03 – Lateral Plate A

**Instructions:**  
Secure the top plate (A05) to the mount structure first, ensuring all cabling is in place. Then attach the bottom plate (A06) and the remaining lateral plate (A03) to complete the enclosure.

___

## Final Adjustments and Output Flange

### 🔧 Step 17: Install Output Flange and Vixen Plate

<div style="flex: 1; max-width: 200px;">
  
  
</div>

**Parts:**
- A11 – Output Flange
- S06 – M3x30 Screws (x12) 
- C18 – Vixen Plate
- S08 – M5x10 Screws (x4) 

**Instructions:**  
Install the output flange (A11) onto the RA reducer. Then, mount the Vixen plate (C18) securely.

🎉 You have now fully assembled your HEMY mount!

___

## ✅ Final Checklist Before First Use

- [ ] All mechanical screws are tightened
- [ ] Belts are properly tensioned on both RA and DEC
- [ ] All pulleys are aligned and set screws are secure
- [ ] The output flange and dovetail clamps are solidly mounted
- [ ] Brake is mounted and functional
- [ ] GPS and antennas are installed and connected
- [ ] Power wiring is secured and routed cleanly
- [ ] All PCBs are installed and correctly connected
- [ ] No stray cables or obstructing elements
- [ ] RA and DEC axes can rotate freely with appropriate torque on motors

___

## 🧠 Flashing OnStepX Firmware

HEMY is designed to run with **OnStepX**, an open-source controller firmware for astronomical mounts. Flashing the firmware is simple, but depends on your hardware configuration (Teensy, STM32, ESP32, etc).

### Basic Steps:
1. **Download OnStepX** from the [official GitHub repository](https://github.com/hjd1964/OnStepX)
2. **Open the firmware** in [PlatformIO](https://platformio.org/) (VSCode plugin)
3. **Edit `Config.h` and `Board.h`** to match your HEMY configuration (stepper drivers, gear ratios, brake, etc)
4. Connect your board via USB
5. Click **Upload** in PlatformIO to flash the firmware
6. Open the **serial monitor** and confirm initialization (check RA/DEC movements, homing, etc)

> 💡 Tip: Refer to the `pcb_assembly.md` file for hardware pin mapping and settings.

Once the firmware is flashed and the mount is powered, you’re ready to configure OnStep via Wi-Fi, serial, or compatible astronomy tools (INDI, ASCOM, etc).

___

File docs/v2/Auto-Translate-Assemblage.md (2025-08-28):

# ⚠️ Travail en cours - Guide d'assemblage en cours!

> ** Ce guide d'assemblage est toujours en cours d'écriture et améliorée. **
>
> Certaines étapes peuvent être manquantes, incomplètes ou mises à jour bientôt.
>
> Si vous construisez Hemy, veuillez lire attentivement, partager les commentaires et
> Vérifiez l'onglet [Discussions] (https://github.com/polvinc/hemy/discussions) pour l'aide et les mises à jour.

---

# Guide d'assemblage Hemy V2 Hemy V2

Ce document vous guide à travers l'assemblage mécanique du support équatorial Hemy V2. Chaque section comprend des pièces, des instructions et des conseils suggérés requis.

---
## Vue des pièces globales

Les différentes parties qui seront utilisées dans le manuel actuel sont présentées ici regroupées par des groupes d'assemblage. (Par exemple: pour la vis)
Overall presentation
[Image pleine grandeur](./pictures/2025-HEMY_disassembled-01.jpg)

Surtout, n'hésitez pas à ouvrir le [Projet surhape 3d] (https://cad.onshape.com/documents/5bb7abe94ccc1dfccd880b05/w/c4dcfbc560d188df ACA97350 / E / 5198383ED1B9D7F502F35102? Rendermode = 0 & uistate = 6808b73883ed3655f234ab55) En parallèle, afin que vous puissiez observer les subtilités de l'assemblage, les détails de l'assemblage et les sous-ensembles.

---

## Assemblage de l'axe (partie commune)

### 🔧 Étape 1: Installation de la poulie réductrice harmonique

<div style="flex: 1; max-width: 200px;">
  
  
</div>

**Parties:**
- C06 - Réducteur harmonique ZXK17-100 (x2)
- A12 - Poulie principale (70T) (x2)
- S07 - CONE Point Hex Socket Set M3X3 (x12)
  
**Instructions:**
- Poulie Forach (70T) et réducteur harmonique
- Assurez-vous une orientation correcte des vis - reportez-vous au modèle 3D si nécessaire.
- Remplacez la douille hexadécimale du point de cône (vis d'origine des vis de pression expédiées par le réducteur) par des plus courtes et modifiez leur orientation pour pousser à l'extérieur.
- Fixez la poulie principale à 70 dents (A12) à l'un des réducteurs harmoniques (C06).

Remarque: les vis d'origine des vis de pression expédiées avec le réducteur ont été remplacées par des plus courtes.

Remarque: vous avez besoin de l'outil T01 (clé Allen).

---

## Assemblage de l'axe RA

### 🔧 Étape 2: Réducteur de montage au cadre principal

<div style="flex: 1; max-width: 200px;">
  
  
</div>

**Parties:**
- A01 - Frame principale A (X1)
- C10 - Vis d'angle carré M4 (x2)
- S19 - Vis M4X8 (x2)
- S06 - Vis M3X30 (X7)
- S02 - rondelles M3 (X7)
- S10 - M3 NUTS (X7)

**Instructions:**
Corrigez deux cubes d'angle carré M4 (C10) sur le cadre principal A (A01) à l'aide d'une vis M4x8 chacune. Installez ensuite le réducteur (C06) à l'aide de vis M3x30 avec rondelles et écrous.

- Vérifiez l'orientation du réducteur en identifiant ses vis et en les orientant comme dans l'image.

- Vérifiez l'alignement du réducteur.

En raison de la nécessité de s'assurer que le réducteur s'intègre dans l'espace, une petite marge a été prise. Par conséquent, il est important de vérifier qu'il y a autant d'espace entre le réducteur et la plaque principale de chaque côté.
  
> Astuce: un outil de centrage imprimé en 3D peut être utile pour un alignement parfait. (À construire.)
>
> Astuce: Mettez la même feuille de papier pliée sur quatre côtés du réducteur.

- Une fois le réducteur en place, retirez les deux vis indiquées en bleu sur la photo (pour le support de frein ultérieur).

---

### 🔧 Étape 3: sous-assemblage de freinage

<div style="flex: 1; max-width: 200px;">
  
  
</div>

**Parties:**
- C08 - Arbre 5x45 mm-grince à plat
- A07 - Support des freins (x2)
- C15 - Frein (SWB-003) (x1)
- C05 - Roulement 625zz (x2)
- S03 - Washer M5 (x2)
- C01 - Pulley GT2 16T (X1)

- C12 - Spacer M3X19mm FF (x3)
- S05 - Vis M3X10 (X3)
  
- S04 - Vis M2X10 (x2)
- S01 - Washer M2 (x2)
- C04 - ceinture GT2 - 200 mm

**Instructions:**

#### 🔧 Étape 3.1: Sous-assemblage de l'arbre:
1. Le meulage de l'arbre est insuffisant. Il est nécessaire de compléter ce meulage pour s'intégrer dans la pièce de connexion de frein. Effectuez meulage sur toute la longueur de l'arbre.
2. Sur une pause, Assistance Assemblez l'espaceur avec des vis M3.
3. Ensuite, à partir de ce support, assemblez de gauche à droite sur l'arbre (Remarque: La courroie doit être insérée pour contourner la poulie):
1. Break Support
2.
3. Rendance M5
4. Poulle GT2 (serrez-la avec la vis de poulie).
5. laveuse
6.
7. Break Support
4. Visser la dernière rupture du support de l'espaceur.
5. Dévissez la vis de la poulie de sorte que l'extrémité de la barre ne dépasse pas au-delà du bord du support de frein lorsque la poulie repose sur le support de freinage.
6. Insérez la pièce de connexion de frein de l'autre côté de l'arbre afin qu'il soit aussi proche que possible du support sans le toucher (marge de 1 mm).

Le résultat doit être cohérent à ce qui suit (sauf pour la ceinture qui doit avoir été insérée et ne peut pas être vue ici):

Description of the image

#### 🔧 Étape 3.2: Préparation de rupture:
Les vis de connexion de la rupture doivent être remplacées par des vis M2 plus longues.

Description of the image

Pour cela, vous devez dévisser les vis suivantes.

Description of the image

Comme ces vis sont fortement serrées, vous aurez besoin d'un conducteur à vis solide. Vous serez prudent en dévissant, pour éviter que les ressorts internes sortent de sortir de leur logement.

Remplacez les vis par les vis M2.

#### 🔧 Étape 3.3: Résultats finaux:

Les résultats doivent ressembler:

Description of the image

Montez le frein (C15) sur sa plaque de support supérieure (A07) à l'aide de trois entretoises M3x19 mm et des vis M3x10. Utilisez des rondelles et des vis M2 si nécessaire pour l'interface électrique. Installez la poulie GT2 16T (C01) sur l'arbre de frein.

---

### 🔧 Étape 4: assemblage RA et tension de la courroie

<div style="display: flex; flex-wrap: wrap; justify-content: space-between; max-width: 100%;">
  <div style="flex: 0 0 48%; max-width: 48%; margin-bottom: 10px;">
    
    
    
</div>
  <div style="flex: 0 0 48%; max-width: 48%; margin-bottom: 10px;">
    
    
    
</div>
</div>

<div style="display: flex; justify-content: center; max-width: 100%;">
  
</div>

**Parties:**
- A07 - Support des freins (X1)

- A08 - Support moteur (X1)
- C04 - ceinture GT2 200 mm (x1)
- C02 - Pulley GT2 20T (x1)
- C07 - moteur NEMA17 (X1)
- C11 - Spacer M3X21mm FM (x3)
- S15 - Vis M3X35 (x2)
- S06 - Vis M3X30 (x2)
- S10 - M3 NUTS (X4)

**Instructions:**
C'est l'étape la plus délicate - prenez votre temps!

1. Préparez le moteur NEMA17 (C07) avec la poulie GT2 20T (C02) et trois entretoises M3x21mm (C11).
2. Positionnez la courroie (C04) autour de la poulie de frein (C01).
3. Fermez l'assemblage avec le support inférieur des freins (A07).
4. Placez le support du moteur (A08) sur le moteur.
5. Fixez légèrement le moteur au réducteur à l'aide d'une vis (bleu indiqué sur la photo) - ne serrez pas encore complètement.
6. Montez le frein sur le réducteur à l'aide de deux vis et écrous M3X35.
7. Insérez les deux dernières vis (rouge sur photo) et réglez soigneusement la tension de la courroie.

🎉 Félicitations! Le sous-assemblage de l'axe RA est maintenant complet - la partie la plus difficile est terminée!

---

## Assemblage de l'axe DEC

### 🔧 Étape 5: Installation principale de la poulie

<div style="flex: 1; max-width: 200px;">
  
  
</div>

**Parties:**
- C06 - Réducteur harmonique ZXK17-100 (x1)
- A12 - Poulie principale (70T) (x1)

**Instructions:**
Comme à l'étape 1, fixez la poulie principale 70T au deuxième réducteur harmonique. Assurez-vous l'orientation correcte des vis - consultez le modèle 3D. Utilisez les vis de pression de remplacement plus courtes fournies.

---

### 🔧 Étape 6: Attachez les cubes au cadre principal B

<div style="flex: 1; max-width: 200px;">
  
  
</div>

**Parties:**
- A02 - Frame principale B (x1)
- C10 - Vis d'angle carré M4 (x6)
- C19 - M48 Screvs (HS)

**Instructions:**
Fixez les six cubes d'angle M4 (C10) au cadre principal B (A02) à l'aide de vis M4X8.

---

### 🔧 Étape 7: réducteur du mont Dec

<div style="flex: 1; max-width: 200px;">
  
  
</div>

**Parties:**
- S06 - Vis M3X30 (X9)
- S02 - Laveuses M3 (X9)
- S10 - M3 NUTS (X9)

**Instructions:**
Centre le réducteur harmonique avec sa poulie sur le cadre principal B (A02) et fixez-le à l'aide de vis M3X30 avec des rondelles et des écrous.

Assurez-vous d'orienter correctement le réducteur harmonique dans la partie principale, en utilisant les vis de réducteur comme points de référence.

Notez que deux de ces vis seront retirées et remplacées dans une étape décrite ci-dessous par des vis qui maintiendront le moteur. (Voir photo en bas à gauche).

Avant de procéder à l'extraction de ces vis, assurez-vous que les 9 vis de connexion du réducteur harmonique et la partie principale sont étroitement sécurisées.

> Astuce: un gabarit d'alignement imprimé en 3D est également utile ici.

Une fois aligné et fixé, retirez les deux vis à marquage bleu du réducteur (comme indiqué sur la photo).

---

### 🔧 Étape 8: Préparer l'assemblage du moteur

<div style="flex: 1; max-width: 200px;">
  
  
</div>

**Parties:**
- C07 - moteur NEMA17 (X1)
- C02 - Pulley GT2 20T (x1)
- C03 - ceinture GT2 166 mm (x1)
- C11 - Spacer M3X21mm FM (x3)
- S16 - tête de bouton de douille M3X5 (x3)

**Instructions:**
Montez la poulie GT2 20T sur l'arbre du moteur NEMA17. Ajouter les trois entretoises de 21 mm et installer la ceinture GT2 de 166 mm.

---

### 🔧 Étape 9: Moteur monte en réducteur

<div style="flex: 1; max-width: 200px;">
  
  
  
</div>

**Parties:**
- S15 - Vis M3X35 (X1)
- S02 - Laveuses M3 (X1)
- S10 - M3 NUTS (X1)
- S13 - Vis M3X16 (x2)

**Instructions:**
Positionnez l'assemblage du moteur sur le réducteur. Utilisez les vis M3X35 et les vis M3X16 pour tout fixer et tendre la ceinture en conséquence.

🎉 L'axe DEC est maintenant entièrement assemblé!

---

## Ensemble de trame d'axe

### 🔧 Étape 10: Connectez les axes RA et DEC

<div style="flex: 1; max-width: 200px;">
  
  
  
</div>

**Parties:**
- A01 - Frame principale A (côté RA)
- A02 - Cadre principal B (côté déc.)
- S18 - Vis M4X10 (x4 ou plus au besoin)

**Instructions:**
Positionnez les sous-assemblages RA et DEC pour former un angle droit (90 °) entre les deux plaques d'image principales (A01 et A02). Alignez les trous de montage correspondants et fixez-les de manière lâche à l'aide de vis M4X10.
> ⚠️ ne serrez pas complètement les vis - le carré final et le renforcement se feront avec les plaques latérales à des étapes ultérieures.

---

## Assemblage d'aronde

> ⚠️ Remarque: L'électronique USB et DC Passthrough pour la queue d'aronde est toujours expérimentale et n'est pas entièrement testée.

### 🔧 Étape 11: Attachez l'électronique et la couverture

<div style="flex: 1; max-width: 200px;">
  
  
</div>

**Parties:**
- B01 - Couverture de PCB en queue de doute (X1)
- PCB07 - Carte de pashrough Dovetail (expérimental)
- A09 - Vixen / Losmandy Dovetail (X1)

**Instructions:**
Positionnez le PCB Passthrough sur l'adaptation (A09) et fixez la couverture imprimée en 3D (B01) comme indiqué.

---

### 🔧 Étape 12: Mount Dovetail sur DEC REDUCER

<div style="flex: 1; max-width: 200px;">
  
</div>

**Parties:**
- S06 - Vis M3X30 (x2)

**Instructions:**
Rachetez les câbles à travers la découpe centrale du réducteur, puis fixez la queue d'aronde (A09) vers le réducteur DEC à l'aide de vis M3X30.

---

### 🔧 Étape 13: Installer des pinces

<div style="flex: 1; max-width: 200px;">
  
  
</div>

**Parties:**
- A10 - RFIX Dovetail Pramps (X2)
- C20 - Vis de bouton M6X40 avec ressorts (x2)

**Instructions:**
Insérez les deux pinces (A10) dans la queue d'aronde (A09), fixez-les à l'aide des vis et des ressorts du bouton M6X40.

🎉 L'interface Dovetail est désormais installée et prête à tenir votre télescope!

---

## Plaques latérales et électronique

### 🔧 Étape 14: Monter la plaque latérale B et cadre sécurisé

<div style="flex: 1; max-width: 200px;">
  
  
</div>

**Parties:**
- A04 - Plaque latérale B (x1)
- S19 - Vis M4X8 (au besoin)

**Instructions:**
Fixez la plaque latérale (A04) au cadre RA / DEC pour compléter le support carré. Une fois aligné, serrez toutes les vis auparavant lâches pour fixer la structure globale.

---

### 🔧 Étape 15: Installez l'électronique supérieure

<div style="display: flex; margin-bottom: 5px;">
  
  
</div>

<div style="display: flex;">
  
  
</div>

**Parties:**
- Tous les PCB (assemblés, voir __code0__)
- C13 - Spacer M3X8MM FF (X4)
- poignée, antenne GPS, couverture GPS

**Instructions:**
Installez deux cubes d'angle M3 sur la plaque supérieure. Montez le PCB assemblé principal (y compris le conducteur de frein, les TMC5160 et les teensy) sur la plaque supérieure à l'aide des espaceurs M3X8. Installez la poignée et les antennes (Wi-Fi et GPS) et placez le couvercle de l'antenne GPS (B02).
Assurez-vous que tous les câbles sont connectés et acheminés proprement.

---

### 🔧 Étape 16: Assemblage final des plaques supérieures / inférieures / latérales

<div style="display: flex; margin-bottom: 5px;">
  
  
</div>

<div style="display: flex;">
  
  
</div>

**Parties:**
- A05 - plaque supérieure
- A06 - Plaque inférieure
- A03 - Plaque latérale A

**Instructions:**
Fixez d'abord la plaque supérieure (A05) à la structure de montage, en vous assurant que tout le câblage est en place. Fixez ensuite la plaque inférieure (A06) et la plaque latérale restante (A03) pour compléter l'enceinte.

---

## Réglages finaux et bride de sortie

### 🔧 Étape 17: Installez la bride de sortie et la plaque de renard

<div style="flex: 1; max-width: 200px;">
  
  
</div>

**Parties:**
- A11 - Bride de sortie
- C18 - plaque de renard

**Instructions:**
Installez la bride de sortie (A11) sur le réducteur RA. Ensuite, montez en toute sécurité la plaque de VIXEN (C18).

🎉 Vous avez maintenant pleinement assemblé votre monture hématique!

---

## ✅ Liste de contrôle finale avant la première utilisation

- [] Toutes les vis mécaniques sont serrées
- [] Les ceintures sont correctement tendues sur la PR et le Dec
- [] Toutes les poulies sont alignées et les vis de réglage sont sécurisées
- [] La bride de sortie et les pinces à queue d'aronde sont solidement montés
- [] Le frein est monté et fonctionnel
- [] GPS et les antennes sont installées et connectées
- [] Le câblage d'alimentation est sécurisé et acheminé proprement
- [] Tous les PCB sont installés et correctement connectés
- [] pas de câbles errants ou d'éléments obstrués
- [] Les axes RA et DEC peuvent tourner librement avec un couple approprié sur les moteurs

---

## 🧠 clignoter le firmware Onstepx

Hemy est conçu pour fonctionner avec ** onstepx **, un firmware de contrôleur open source pour les supports astronomiques. Le clignotement du firmware est simple, mais dépend de votre configuration matérielle (Teensy, STM32, ESP32, etc.).

### Étapes de base:
1. **Download OnStepX** from the [Référentiel officiel de GitHub](https://github.com/hjd1964/OnStepX)
2. **Open the firmware** in [Plateforme](https://platformio.org/) (VSCode plugin)
3. ** Modifier __code0__ et __code1 __ ** pour correspondre à votre configuration hémy (conducteurs de stepper, ratios de vitesse, frein, etc.)
4. Connectez votre planche via USB
5. Cliquez sur ** Télécharger ** dans Platformoo pour flasher le firmware
6. Ouvrez le moniteur de série ** ** et confirmez l'initialisation (vérifiez les mouvements RA / DEC, Homing, etc.)

> 💡 Astuce: reportez-vous au fichier __code0__ pour le mappage et les paramètres du brochement matériel.

Une fois le micrologiciel flashé et le support, vous êtes prêt à configurer le surpapé via des outils d'astronomie Wi-Fi, en série ou compatibles (INDI, ASCOM, etc.).

---

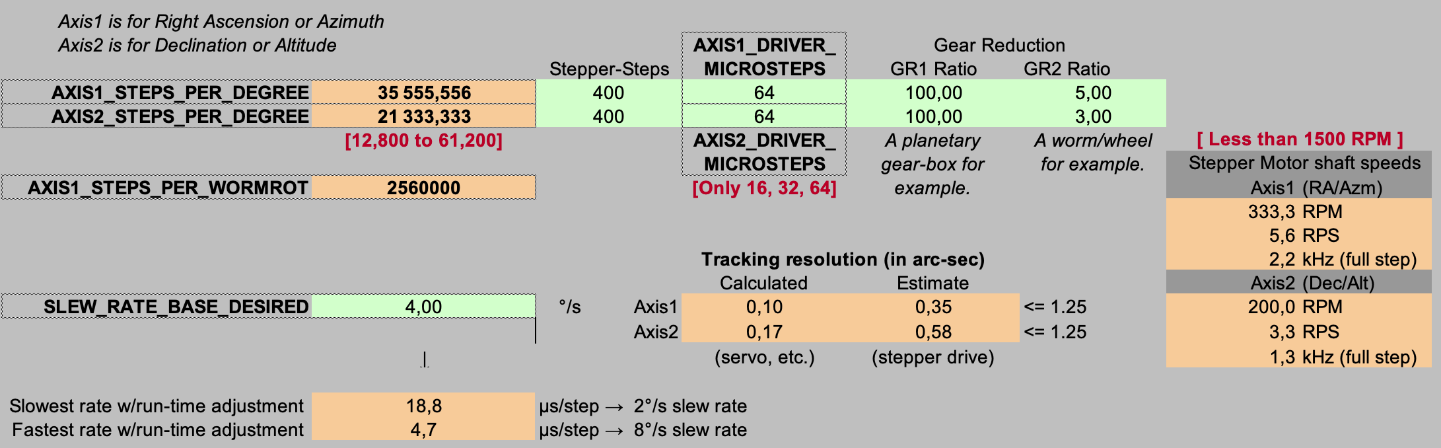
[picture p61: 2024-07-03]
images/OnStep_calc.png

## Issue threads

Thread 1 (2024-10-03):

Has HEMY ever been actually made?

martin0359, 2024-10-03:
Hi Polvinc, HEMY looks like the better design, but DHEM offers a more cost-effective way of thinking about it. I would like to know if the dimensions of the HEMY parts are accurate and I would like the CNC machining to be done in one time. If they are not verified, should I make the DHEM first?I already have a tiny experience of making a 3d printed Keen eq mount once.

polvinc, 2024-10-05:
That's a good question!
In practice, HEMY outperforms DHEM. I was able to test the latter this summer, and I made two of them. I'm achieving tracking performance of less than 1 arcsec with a load of around 13kg, with no counterweight. Here's an example image taken with HEMY (I don't have any excellent astrophoto equipment, just a Nikon D750 that I defiltered myself, and a Sigma 150-600mm; for this image I used 50x5min exposure, ISO1600, 400mm f7.1, with DOF).
<a href="https://ibb.co/svfyDsq">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</a><br /><a target='_blank' href='https://imgbb.com/'>IC1396</a><br />

Following these tests, I made a few minor modifications to HEMY mount, which are worth waiting for the plans to be updated before starting to build it. I'm also in the process of developing HEMY's electronics, which will be integrated into it, and above all will be able to manage the brake (which is not currently the case with separated onstep). The development will be ready in two or three months (joint work with an acquaintance, https://github.com/zUrp-Astronomics/unicorn).

In the meantime, if this is your first DIY project with this level of investment, I'd recommend starting with DHEM. You can use the same gearboxes as the HEMY (on aliexpress). You can then use them for the HEMY.

It's taking me a while to reply, but don't hesitate to ask questions, even simplistic ones!

martin0359, 2024-10-06:
Thank you, Polvinc, I couldn't resist CNC all the parts of the HEMY main body when i waiting for your reply, and I expect to receive it after 7 days.The AZ BASE part I am going to buy the finished product, I'm in China and expect the overall cost to be much lower than you anticipate.I'd also like to test some harmonic driver that made in China.I have studied the drawings carefully and like the HEMY design even more.

More questions will be communicated to you during the build, thanks again for your great design. By the way do the new improvements require all the parts to be reCNC?

martin0359, 2024-10-06:
No. 11, “diameter 8 shaft”, what is this part made of and what is its length?

martin0359, 2024-10-06:
Also the bom list in readme.md seems to have a different motor model than in the pdf and is missing the belt.
Which is the necessary setup?

polvinc, 2024-10-06:
Glad to hear you're getting into manufacturing! I'd love to hear your feedback on assembly and performance testing!

No, the improvements do not require any machining modifications to the frame. The main changes concern the ALT/AZ base.
On the other hand, as this was the first build, I took quite a few liberties in adjusting the coupling between the harmonic gearbox and the motor. In particular, the spacing between the wave generator and the bearing. It's currently missing a stop at the right dimension.
I used M8 wide washers for this, as well as shim-seal washers:
https://fr.aliexpress.com/item/1005001481545326.html
https://fr.aliexpress.com/item/1005002374937009.html

To assemble, attach the shaft (phi 8mm, length 40mm, https://fr.aliexpress.com/item/1005006559769183.html) to the wave generator. This assembly is inserted into the flex spline of the harmonic gearbox, with the shaft pressure screws on the gearbox side.
Then fit the backlash adjustment washers (one M8x24x2 wide, and four M8x14x0.1mm). The wide washer will be used to support the bearing. Clearly, this part will eventually be replaced by a machined part.
Then, this assembly (complete gearbox + shaft + washers) is inserted into the bearing with part number 9 on the drawing, and the assembly is locked in translation with the pulley.
I use pulleys:
- For RA: 80-tooth pulley, 180-tooth GT2 belt, 16-tooth motor side
- For DEC: 60-tooth pulley, 150-tooth GT2 belt, 16-tooth motor side

As for the engines, I haven't bothered for the moment, I've taken two that I had in stock: https://www.omc-stepperonline.com/fr/biaxial-nema-17-bipolaire-0-9deg-44ncm-62-48oz-in-1-68a-2-8v-42x42x48mm-4-fils-17hm19-1684d
The important thing for the resolution is that they must be at 0.9° pitch.

polvinc, 2024-10-06:
What's certain is that I'll have to produce a more detailed doc, and provide the test results. The weather in France at the moment is totally unsuitable for astro photography.

Cepadues, 2024-10-06:
> As for the engines, I haven't bothered for the moment, I've taken two that I had in stock: https://www.omc-stepperonline.com/fr/biaxial-nema-17-bipolaire-0-9deg-44ncm-62-48oz-in-1-68a-2-8v-42x42x48mm-4-fils-17hm19-1684d The important thing for the resolution is that they must be at 0.9° pitch.

Are you satisfied with their current performances, or would you pick another one if you had to build more HEMYs ?

polvinc, 2024-10-06:
> Are you satisfied with their current performances, or would you pick another one if you had to build more HEMYs ?

Yes, they weren't chosen at random either. They have enormous torque and very satisfactory angular resolution. The only drawback is their weight. You could imagine making a slightly lighter mount by reducing the weight of the motors, especially if you wanted to carry less load. For my purposes, I won't be changing. The HEMY in this configuration weighs 5kg with its base, and can support >13kg according to my initial tests (15kg according to theory, 20kg with cw).

polvinc, 2024-10-06:
The next objective is to test HEMY's guidance performance. After adding shims to better hold the wave generator, I should potentially be able to go lower than the 1 arcsec I achieved this summer.
I also think that some gearboxes must be better than others. I'll have to test that one day.

Cepadues, 2024-10-06:
5kg including base is still light for an harmonic mount ! That's the same as an EQM-35 which can do 10kg MAXIMUM and guides far worse than your HEMY.
I hope the weather in France becomes nicer ;)
Have a nice evening

martin0359, 2024-10-07:
Glad to hear you shared this, it basically solves most of my doubts.
I am using a Chinese product s17-100 harmonic driver, which seems to have more load capacity than the Japan product and costs just under $50 USD, but I will test the actual results.
Do these motors have to be planetary motors? I see in another project you used planetary motors.
For the AZ BASE, I plan to used a finished product that only requires replacing your quick release plate section.

martin0359, 2024-10-10:
Is there a way to convert rj45 to gx12 please? Unluckily my Onstep controller that I already own only have 2 gx12 ports. By the way what are the benefits of using rj45? If it's convenient, could you design a gx12 version for the T plate, my modeling skills are weak. This would help speed up my assembly process, much appreciated!

martin0359, 2024-10-10:
By the way, when will a stable version of Unicorn be released?

Cepadues, 2024-10-10:
You'd have to modify the T PLATE (5), GX12 just needs a round hole right ?

If so I could model it quickly from the plans in the repo, remind me on Sunday if you haven't heard of me.

polvinc, 2024-10-16:
> Do these motors have to be planetary motors? I see in another project you used planetary motors.
No, here the reduction ratio is more than sufficient to dispense with an additional planetary gearbox (which would bring backlash).
> By the way, when will a stable version of Unicorn be released?I can also help with testing if I can
A few months from now. I'm working on other things at the same time, and we also have to make progress on the electronics for the HEMY brake.
> Is there a way to convert rj45 to gx12 please? Unluckily my Onstep controller that I already own only have 2 gx12 ports. By the way what are the benefits of using rj45? If it's convenient, could you design a gx12 version for the T plate, my modeling skills are weak. This would help speed up my assembly process, much appreciated!
The simplest solution is to make your own cable, otherwise you can 3D print or machine a plate to replace the Top Plate with the connectors you like.

martin0359, 2024-10-16:
> You'd have to modify the T PLATE (5), GX12 just needs a round hole right ?
>
> If so I could model it quickly from the plans in the repo, remind me on Sunday if you haven't heard of me.

I think it will have 2 holes,thx.

Cepadues, 2024-10-16:
Here you go,

I assumed the diameter of the holes were 12 mm (from the name of the connector).
Be aware that the holes are untapped, and I'd recommend printing it before sending to a CNC shop to check dimensions are correct.

[Archive.zip](https://github.com/user-attachments/files/17400891/Archive.zip)

This issue is turning into a conversation, maybe it could be moved to a discussion instead ?

martin0359, 2024-10-18:
THX Cepadues
Thanks so much for avoiding me making a gx12 to rj45 cable!
This option is flexible

martin0359, 2024-10-18:
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

I agree with that

Closed 2024-12-03.

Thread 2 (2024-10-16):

[TechDraw] Missing dimensions on the tech drawings

Gophen, 2024-10-16:
Hi,
This issue could be used to report any missing dimension(s) from the technical drawings.

Example :
- Part : T-Plate
- Feature : bottom 2 mounting holes
- Dimension : Height from the bottom of the part
- Dimension in the plan : None, expected 10 mm like at the top
- Correction : Add dimensions as follows (or just give the height of the rectangle) :

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

What do you think ?

polvinc, 2024-10-19:
It's a great idea, thx! It'll help me with my proofreading, and above all it'll get me motivated to make the corrections!

Closed 2024-12-08.

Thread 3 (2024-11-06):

Progress and some emerging issues

martin0359, 2024-11-06:
Dear Polvinc
I apologize for the three week delay, most of the parts were in place three weeks ago, but it wasn't until today that I finished  the assembly basicly.
I still have a few minor questions, starting with the simplest one.
1.Pin definition of motor including brakes (with rj45's, in the end I still used the rj45)
2.The part in the photo I couldn't get the screws on, the holes for the square CNC part underneath that is used to hold it in place don't seem to be quite accurate and I forgot to tap thread to this hole, it's held against another large head screw that seems to be tightened up and doesn't seem to interfere with the operation of the system. The other reason I didn't put the screws in was the belts were already over tensioned and I was worried about breaking them. Do you have any suggestions for this part of the tuning and assembly?
3.If possible, please check the other assembly details for me and ask questions, I hope this won't waste too much of your time!
4.Regarding those brakes, what are my options for testing and controlling them at this stage?

Finally, thank you and your partners for your great creations and unstinting sharing, bringing intellectual enjoyment to us across the ocean.
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

martin0359, 2024-11-06:
About the assembly location of the washers, could you please label in detail, I'm only using three thin washers right now and it seems to complete. I'm not sure what problems this could cause.

polvinc, 2024-11-11:
Wow, that's a great achievement, I'm glad you went all the way with it.

> 1.Pin definition of motor including brakes (with rj45's, in the end I still used the rj45)

For the RJ45s, you need to refer to the electronics you are going to use (in my case, OnStep minipcb2). The HEMY electronics (with brake management) will have WIFI, USB C, and DC 12-25V jack input. A new plate will have to be machined to remove the new connectors.

>2.The part in the photo I couldn't get the screws on, the holes for the square CNC part underneath that is used to hold it in place don't seem to be quite accurate and I forgot to tap thread to this hole, it's held against another large head screw that seems to be tightened up and doesn't seem to interfere with the operation of the system. The other reason I didn't put the screws in was the belts were already over tensioned and I was worried about breaking them. Do you have any suggestions for this part of the tuning and assembly?

What length belt did you use? On the HEMYs I've built, I've never had any problems tensioning the belts or fitting this screw. On the DEC, however, there isn't much margin to insert the screw, so the groove would have to be enlarged. Suggestions I can make:
1. tap the M3 hole
2. enlarge the hole to diameter 4, and insert an M3 nut underneath.
3. In itself, two anchor points for the motors might be enough, it's up to you. My opinion is that I think two spacers only for the support are a bit light.
4. Also, on some of my spacers, I had the impression that they weren't perfectly orthogonal to the plane of their thread, is this the case for yours?

>3.If possible, please check the other assembly details for me and ask questions, I hope this won't waste too much of your time!

The only thing I can see are the M5 (half?) nuts you use. Personally, I designed HEMY with square T-nuts for 2020 profiles, diameter M5. For example: https://fr.aliexpress.com/item/32964780472.html

>4.Regarding those brakes, what are my options for testing and controlling them at this stage?

As long as the electronics dedicated to HEMY are not in place, there is no easy way to manage the brakes. I played with the brake simply by sending 24V, but also with this small circuit (https://www.electronics-lab.com/project/pwm-solenoid-and-valve-driver-using-drv103/). I think it's worth waiting for the electronics dedicated to HEMY, in the meantime, the brake isn't necessary as long as the setup isn't too heavy and there aren't any power cuts. For the two HEMYs I've built, the brake isn't installed inside.

Please don't hesitate to ask other questions, even if I'm a bit slow to answer (family life, etc :D ...)

polvinc, 2024-12-03:
@martin0359 Were you able to solve any small problems you had during assembly?

Closed 2024-12-24.

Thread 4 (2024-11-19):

Updated design?

chunhaow, 2024-11-19:
Dear Polvinc,

Thank you so much for this great design. Just wondering if you could release the updates/modifications you made to the mount and the base. I plan to CNC the parts and build one soon, and it would be great if I didn't build the outdated version. For the electronics, I can 3d print a top plate and use other solutions. Thanks a lot!

polvinc, 2024-11-19:
Hi, there,
Thanks for your interest in HEMY. I don't have time to commit all the updates yet. One or two more weeks of patience, is that OK with you? I'm still reviewing the electronics and mechanics before publishing.
But here's what it looks like :

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

chunhaow, 2024-11-19:
Thank you so much for the prompt reply! This looks great and promising! Looking forward to your commits.

polvinc, 2024-12-03:
I've just pushed the HEMY 1.1 upgrade, if you're interested in getting started. Mind you, even though I've done a detailed review, I haven't yet received my parts, nor the electronics. I should receive everything next week. So the work is not yet totally validated!

chunhaow, 2024-12-04:
Thanks a lot! I plan to CNC the parts soon, but have a few questions:

1. I saw the base parts have 2D drawing. I am wondering if you could also provide the 2D draws for the mount parts. Without these draws, they cannot figure out the diameters of the holes and where to tap threads, etc.

2. For the PCB, I can just build it from https://oshwlab.com/lordzurp/teenastro-redux right?

3. But what about the brake driver. Is it available somewhere?

Thanks again!

polvinc, 2024-12-04:
You're right, I haven't finished the “clean” drawings for the mount yet. For my machining, I did it case by case. Properly detailed drawings shouldn't take too long to be pushed onto the git, I'm on it.

As for the electronics, the TeenAstro Redux project we finished with LordZurp is not yet officially published, since we haven't yet been able to really test the electronics (especially the Brake Driver part). Nevertheless, I've put the Gerbers on the git (TeenAstro Redux, Brake Driver, and Smart Hand Controller). At your own risk if you start manufacturing before our tests! I made the PCBs with JLCPCB. Since I'm receiving my batch of pcb's by this WE, we should be releasing the official project shortly.

polvinc, 2024-12-04:
> 1. I saw the base parts have 2D drawing. I am wondering if you could also provide the 2D draws for the mount parts. Without these draws, they cannot figure out the diameters of the holes and where to tap threads, etc.

--> Done

Closed 2024-12-04.

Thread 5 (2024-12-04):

3d printed instead of CNC?

Trigger-broom-289, 2024-12-04:
Your project has to be the best open source harmonic drive mount I've seen so far.
Do you think the parts which are supposed to be aluminium CNC could be 3D printed? I do have a set of these harmonic drives.

polvinc, 2024-12-04:
I don't really have an opinion on that. In fact, I designed HEMY after DHEM because I thought there was too much bending in the 3D printed parts. So HEMY was designed from the outset to be optimized for CNC, and not for 3D printing. After that, I don't think it's unreasonable to try 3D printing. Just make sure you tweak the infill and other printing parameters to get the most rigid parts possible! Personally, I've 3D printed several versions of HEMY, but that was at the design stage, with draft parameters for printing.

I'm curious to hear if you achieve satisfactory results, let me know!

Trigger-broom-289, 2024-12-04:
I'm going to give it a try, might tweak a few inner parts if I see a weakness.

Closed 2024-12-08.

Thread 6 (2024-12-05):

Questions for parts

chunhaow, 2024-12-05:
Thanks again for pushing the updated design. I have a couple of questions regarding the parts:

1. What's this marked part in the following picture? I didn't find a label for it. It looks like the wave generator of the harmonica drive, but it doesn't have the extrusion like in the second picture.
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

This is the picture of the little extrusion on the wave generator of HBS-17-100
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

I am trying to make sure I am getting the right harmonica drive.

2. How is the handle made? Is it CNCed or can you buy one from somewhere?

Thanks!

polvinc, 2024-12-05:
This is the wave generator. As my design works with HBS and CSF, the drawing is not perfectly representative. But in fact it can be fitted and adjusted! Regarding your image, it turns out that you can turn the wave generator the other way round so that it's flush with the pulley spacer. 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

I had the handle in stock. You can buy it at farnell : [https://fr.farnell.com/mentor/3270-0883/poignee-acier-88mm-noire/dp/4216398](https://fr.farnell.com/mentor/3270-0883/poignee-acier-88mm-noire/dp/4216398). I forgot to put it in the BOM

chunhaow, 2024-12-05:
Thanks for the lightning reply! It makes perfect sense.

chunhaow, 2024-12-06:
One more question: what is the BTR 4 (M5) in the base BOM?

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

I couldn't find it in the assembly picture.

Already placed an order for the CNC parts. Now buying all other parts.

polvinc, 2024-12-06:
This is an allen key (BTR key) for adjusting the base (switching from GEM to Alt/Az, for example). The key can be placed in a special slot and held in place with a magnet.

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

I'm glad to hear that you're starting to make HEMY. Let me know if you have any problems with assembly.

chunhaow, 2024-12-08:
Thanks for identifying the Allen key! One more question:

You said the reduction ratio for DEC was 300:1. But you used 16T and 60T pulleys there. The reduction ratio is actually 3.75:1 instead of 3:1. Or do you actually mean 20T and 60T pulleys for DEC? In either case, is the length of the GT2 belt for this axis still 150mm?

polvinc, 2024-12-08:
Yes, I forgot to modify this part from the early designs... The pulleys are 16T and 60T for DEC. The reduction ratio is **3.75:1** instead of 3:1... **Many thanks for pointing out this (serious!) oversight on my part!** I'd have to change the info on the repo correctly.

I'm closing this issue to avoid adding too much to the diversity of related subjects. Don't hesitate to keep in touch, I'm always interested in feedback on your work!

Closed 2024-12-08.

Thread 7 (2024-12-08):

Input voltage

chunhaow, 2024-12-08:
Do I have to use 24V input for the controller board because of the brake? Can I use 12V (because it's more versatile) if I can find a 12V brake or if use a 12-24 step-up? Do you recommend doing this? Thanks!

polvinc, 2024-12-10:
I haven't finished testing the electronics yet. The input voltage can be between 12 and 24V. The circuit will take care of motor and brake control, with the right voltages.

chunhaow, 2024-12-10:
Thanks! By further investigating the brake pcb, I saw there's a voltage regulator SDB628 which produces 24V output. So it's critical to buy a 24V brake.

polvinc, 2024-12-12:
I did read your message a bit quickly. Yes, you need to use a 24V brake. Also, I've just realised during the first hardware tests of the brake driver card that we made a big mistake upstream of the brake Enable control transistor: we need to add a 4.7k resistor in series... I'll be correcting the layout shortly

chunhaow, 2024-12-12:
Thanks for the update! Some updates on my side: I have ordered all the parts except the PCBs. I should be able to start building in a month.

It would be great to see the final version of the PCBs soon. Can you shed some light on building the PCBs? Do you solder all the components yourself or do you ask JLCPCB to do this? I found it very expensive to have JCL assemble a board, but on the other hand, I am not confident with my terrible soldering skills. Maybe with a stencil, solder paste, and hot air gun, it is manageable?

polvinc, 2024-12-15:
> It would be great to see the final version of the PCBs soon. Can you shed some light on building the PCBs? Do you solder all the components yourself or do you ask JLCPCB to do this? I found it very expensive to have JCL assemble a board, but on the other hand, I am not confident with my terrible soldering skills. Maybe with a stencil, solder paste, and hot air gun, it is manageable?

The cards (osntep and brake) are still being tested. But I hope to share them before the end of the week. Please note that the brake driver card currently available on github has a design error. I've fixed it, but haven't shared it yet. The same goes for the TeenAstro/OnStep board, on which we've moved the GPS connector that was touching the teensy.
As far as manufacturing is concerned, I have to admit that even though I have some soldering skills and a lot of equipment at home, I haven't started soldering myself. At least, not for most of the components. I soldered all the transverse components, but not the rest. We're still talking about a 5x5cm board with 2m of track and nearly 100 components to solder with nearly 400 small table stick pads (including M2 connectors, or 0402s, to solder and check with a magnifying glass).

Closed 2024-12-24.

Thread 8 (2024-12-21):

Alternative control board

chunhaow, 2024-12-21:
Dear Polvinc,

While waiting for your final PCB designs, I couldn't resist thinking about the other modifications of the control board. TeenAstro Redux is great on its own, but it's too expensive to build on JCLPCB (more than $110 USD), because of the number of components that they call "extended". I played around with EasyEDA and came up with a simplification: here I removed ESD protection, wrong polarity protection, and encoder from TeenAstro Redux, changed TCM 2660 to TMC 2209, and used smaller sockets for stepper motors. Now the building cost can be reduced to around $60 USD. I am using the exact outline and connectors with TeenAstro to make sure it will fit in the mount.

Here are the schematic and the PCB picture. Not sure if this whole thing makes sense or I am making some obvious mistakes in the design (first time designing a circuit). Your feedback would be much appreciated!

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

chunhaow, 2024-12-21:
Just realized that your latest pcb is quite different from the files on TeenAstro Redux available here https://oshwlab.com/lordzurp/teenastro-redux. It would be great if you could also share your schematic so that I can make my modifications based on the updated design. Thanks a lot!

polvinc, 2024-12-23:
The updated version of our pcb will be arriving shortly, all we need to do is push it onto oshwlab correctly with the latest proofreading.

chunhaow, 2024-12-24:
> If $110 is too expensive, with all the protection that goes with it, more than 2,500 hours of development by three people whose job it is for some, layout optimisation, thinking about each component (basic or extended), all to support a mounting system that will bring a setup to several thousand euros, I don't really understand your logic.
> All I can say to you is point you in the direction of the onstep forum for your pcb design. But in my opinion, it's far too dangerous and unprotected. Also, what's certain is that the GPS on your layout is going to have trouble picking up its signal (look at layout courses for RF). What's more, the capacitance reserves on the 100uF are strangely placed (they guarantee good power control of the motors). Maybe it'll work, probably it'll be fine, but imagine that it doesn't work the first time: then you're back to $60 (or much more) in engineering. If you want to get into development, I encourage you to do so, it's fascinating, but be careful not to get into the wrong battle: $110 is a small price to pay for development.

Sorry. When I commented "it was expensive to build", I didn't mean to undervalue you and your team's contribution and effort. I truly appreciate your effort to design and build every aspect of this excellent mount. Behind every github and oshwlab commit, there must be countless hours sitting in front of monitors for the mechanical/electronic/firmware designs/debugs and countless hours dealing with the PCB for testing! No value can match what you guys did and what you are sharing with us. All I was saying about the cost is for what I pay JLCPCB for the manufacturing. But I understand that I cannot expect much: this is a DIY project, and the cost cannot be matched with a mass production board.

More importantly, I had a lot of fun doing this. I have learned a lot these days studying circuit and PCB designs, functions of components, and how MCUs and drivers communicate in Onstep. It would be fantastic to see my modifications work eventually (even after a few failures, and I am ready for this). So it's not all about cost at this point.

Thanks a lot for pointing out the errors in my first attempt. I have learned so much from your every single reply. Looking forward to the updated design so that I can make some final corrections of my modifications.

chunhaow, 2024-12-26:
Thanks a lot for uploading the updated design on oshlab! I have made further modifications based on your latest design. I included the protection part and removed the encoder. Then I realized that I didn't need 5v at all because I could feed SHC using 3.3v. So I also removed the 40v->5v converter part! I spent a lot of time studying how MCU is communicating with drivers in onstep (especially from MaxPCB4), and then I rewired the driver by adding some jumpers to support more drivers with legacy/SPI/UART modes.

**Minor questions**: (1) is there any reason for using different inductors and capacitors in the buck converter circuit than what the datasheet recommends? For example, your L3 is 10uH, and your C34, C34 are 10uF; however, the datasheet of AP63203WU-7 recommends using 4.7uH and 22uF for them. (2) your L2 and L3 have a satuation current that is only 880mA. Would this be sufficient for other parts using 5V or 3.3V? Picture attached:

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

Here are my designs. I will do a final review and then send it to JLCPCB. Fingers crossed. Thanks again for the excellent and excellent designs!

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

polvinc, 2024-12-28:
Your design is nice. However, several recommendations: your Teensy MicroMod will touch the GPS component (I made this mistake on the PCB on HEMY's GitHub). You need to pay attention to the 3D model of your complete assembly. Our PCB on oshwlab has corrected this error. As far as the choke and capacitor are concerned, we've adopted a design that we use in our respective companies for step-downs. This design is normally sufficient for the purpose.
Be careful with your motor drivers too, you need to make sure they fit into HEMY, as they take up more space than our original design, and will need to be cooled with a heatsink.

lordzurp, 2024-12-31:
Hi
I did a batch with single 3v3 power for uC and SHC, and when I plugged the
SHC, it make a reset on uC ... That's why I go back to separate 5V for SHC
For the stepper driver, it's cheaper to integrate them on the pcb than buy
discrete driver and it's cleaner integration (IMHO)

Le sam. 28 déc. 2024, 14:57, polvinc ***@***.***> a écrit :

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

lordzurp, 2024-12-31:
Extensive answer

- AP6320x designs
Forked from my company's standardized design, to be compatible with my production line's internal BOM.

- Board's logic consumption: around 300mA

- SHC comsumption: 150mA with 2"42 OLED display

chunhaow, 2025-01-01:
Hi polvic and lordzurp,

Thank you so much for the additional feedback! It's very helpful.

I do have an additional question regarding the GPS connection. I am not sure if you are able to find satellite signals in practice easily, but it looks like the impedance of the track connecting the RF port doesn't have the required 50ohm value. I used the JLC impedance calculator here https://jlcpcb.com/pcb-impedance-calculator and actually, it's impossible to match the 50ohm impedance in a 2-layer PCB (it requires a trace of width 2.7mm). But with a 4-layer PCB (with inner GND layers), it's quite easy: depending on the stack, 0.15-0.35mm width trace would be good.  Is your PCB made in 4 layers?

Also, I noticed a (possibly) error in the PCB design: the sizes of the holds of the M2 connector don't match the component in the BOM. The correct diameters should be 1.6mm and 1.1mm, respectively.
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
danb35, 2025-01-27:
I just quoted out five copies of the main board (based on what's in the repo right now) at JLC, and it came to a little over US$200 (so, about US$40 each).  But this really is begging for some kind of a group buy, because the "standard" PCB assembly (which is required due to some of the part choices) has some significant setup costs (not to mention shipping).  And I expect, though I haven't quoted this out yet, the same is true of the CNC parts.

chunhaow, 2025-01-29:
> I just quoted out five copies of the main board (based on what's in the repo right now) at JLC, and it came to a little over US$200 (so, about US$40 each). But this really is begging for some kind of a group buy, because the "standard" PCB assembly (which is required due to some of the part choices) has some significant setup costs (not to mention shipping). And I expect, though I haven't quoted this out yet, the same is true of the CNC parts.

Some tips to reduce the cost: the parts that prevent economic processing are the power management IC DPS1135-FIA-13, and the center SMD nut. If you are able to solder these two by yourself, the cost will be significantly reduced. The SMD nut is very easy to deal with, while DPS1135-FIA-13 is difficult. You need to use a toothpick to apply a tiny amount of soldering paste to each soldering pad (0.5mm pitch), carefully place the IC, and then use a hot air gun to solder.

polvinc, 2025-02-02:
I agree with chunhaow. We designed this card to be ‘universal’. Not everyone has a €1000 soldering station and suitable equipment at home (I do!). For the time being, maybe one day we'll work out a system for distributing individual cards with a commercial partner, but that's not planned yet.
As far as the mechanics are concerned, it's true that the unit price goes down if you order several HEMYs, and that makes financial sense. That's what I did with people around me who were interested. But you still need to have people around you who are interested in embarking on this project!

The PCB is fully functional and has been tested. I'm very happy with it. I'll have to share the onstep config.h one of these days. The only thing that's left with this electronic board is a bit of operating noise on the motors that's a bit disturbing when tracking, perhaps linked to the TMC2660, which has the good taste of passing a lot of current, but doesn't have on-board silence algorithms like the TMC5160 or TMC2130.

chunhaow, 2025-02-15:
I am happy to report that my board works great. Wifi, Bluetooth, GPS are working. TMC2209 works silently and smoothly in uart mode. I added pull-ups to the enable pins of the stepper drivers, to prevent the brake from getting released during OnStepX is starting up. I like Bluetooth a lot. With it, I can control the mount with my phone without disconnecting from the internet.

My tripod arrives next week. So I can get my telescope on it then and do more tests.

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

polvinc, 2025-02-16:
I'm really pleased that you've managed to get a functional card that meets your expectations! Good idea, the pullups, I'll think about integrating them. As you can see, I'm going to go with your idea of integrated drivers, at least for a while. This will be to validate the rest of the pcb from top to bottom.

I'm very happy you were able to do this, and I'm very interested in getting your feedback as you test. I don't have infinite time to develop designs and test them fully, so your feedback is invaluable.

chunhaow, 2025-02-19:
Hi @polvinc and @lordzurp , I am just wondering if you can receive signals from your GPS antenna. The track width out of your RF port doesn't match the required 50 ohm impedance, so in theory, it's not going to work. But on the other hand, it's just a few millimeters, and it might be fine. I am wondering how things go in practice vs in theory.

polvinc, 2025-02-24:
It's not easy to make a 50 Ohm track on a double layer. I played around with SaturnPCB to find the best configuration. Anyway, it's such a short journey that it doesn't really matter. All the clock cards I've seen being designed at work didn't take that much care over their track impedance when the path to the antenna was so short.

I widened the track by around 1mm to get it closer to the desired impedance. And we're getting good GPS reception with a small external aerial.

What pull-up values did you use?

chunhaow, 2025-02-25:
It's good to know that the impact of impedance is not significant for such a short distance. One option to get the 50ohm impedance is to use a 4-layer PCB, and the manufacturing cost is still the same with JLCPCB.

I should have used 4.7k for the pull-ups as in MaxPCB4 and MaxESP4, but I don't have them in stock, so I used 5k instead.

Closed 2025-04-08.

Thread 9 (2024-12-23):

Harmonic drive ratio

Trigger-broom-289, 2024-12-23:
Hello,

I currently have a couple of 17-30 instead of the 17-100, would that work or do I have to get the 17-100 ratio model?

thanks

polvinc, 2024-12-23:
I advise you to find out about reduction ratios, in relation to the angular resolution of the mount. In your case, a reduction ratio of 1:30 in the main with 1:5 in the pulley (for RA, 1:3.75 for DEC) is a bit tight in terms of real resolution. It will work, but you will have between 1 and 1.5 arcsec of resolution, which is a bit tight for astrophotography with long focal lengths.

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

Trigger-broom-289, 2024-12-23:
Thanks, I'll see if I order some new harmonic drives.

Closed 2024-12-23.

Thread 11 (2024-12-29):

Confusion regarding bom

Kerman-ap, 2024-12-29:
I see two versions of the BOM, the one in the readme and the one in the code files as separate ones for the mount and the base, am I right in saying it's better to follow the BOM in the code files? And would you call those complete?

polvinc, 2025-01-08:
There are indeed several BOMs. In fact, the ones in the PDFs of the frame and base plans were used for the design. The one in the table corresponds more to what I bought to make my HEMYs. It seems to me that the PDFs are more complete than the one in the readme. On the other hand, the one on the readme allows you to buy the parts directly.
I'm not sure if I'm being clear enough...

danb35, 2025-01-29:
If the BOM in the PDFs is definitive, I could submit a PR to update the docs (probably in its own file rather than in the README itself).  Would that be helpful?

danb35, 2025-02-01:
I'm trying to put together an updated BOM, but I'm running into a few questions:
* The README lists a few parts that I don't see in either of the PDFs--not for the mount or for the base.  These are the M6x54 clamping knob/screw, the two M6x50 clamping knob/screws, and the M8x14xThick adjusting shims.  Have these been removed, or am I missing them?
* Motors.  The README links to StepperOnline.com and calls for two identical motors (their model # 17HM19-1684D).  The PDF for the mount lists two separate motors, noting "double shaft" one one but not the other, and a weight difference of ~100g between them, but lists the same model number for both (which is the same model the README links to).  Is this right, or should the one designated D09 have a different model number noted?
* The handle.  I haven't been able to find an equivalent to the Mentor 3270.0883 on Aliexpress, but maybe I'm not searching for the right thing.  Are you aware of an alternative?
* The Vixen/Losmandy dovetail clamp.  Is there a particular part you had in mind, or can I just pick one more or less at random from Aliexpress and expect the screw hole pattern to line up?
* What about a counterweight shaft?  I recognize it won't be needed for most use, but is this designed to fit a particular off-the-shelf shaft?
* The SHC.  I see you've redesigned the PCB for it compared to the one in the TeenAstro project, but I assume it still needs a Wemos D1 Mini v4.0, along with the 2.4" OLED display?  Theirs calls for an I2C display, but the seven-pin connector you call for makes me wonder if your design needs SPI instead.  Though from the STEP file it appears you're only using a 4-pin header to connect to the display.
  * It also looks like your design is missing three buttons compared to theirs: Shift, f, and F.  Are these implemented differently?  Are you using different code for the SHC?  Or am I just missing them?
  * Is there an enclosure model available?  I presume the idea is that it would be 3D-printed.

This looks like a great project, and I'm looking forward to getting started (and hopefully helping with the docs some).

chunhaow, 2025-02-01:
> I'm trying to put together an updated BOM, but I'm running into a few questions:
>
> * The README lists a few parts that I don't see in either of the PDFs--not for the mount or for the base.  These are the M6x54 clamping knob/screw, the two M6x50 clamping knob/screws, and the M8x14xThick adjusting shims.  Have these been removed, or am I missing them?

The clamping knob/screws in the PDF are good. The M8x14 shims are no longer needed in v1.1 (I think).

> * Motors.  The README links to StepperOnline.com and calls for two identical motors (their model # 17HM19-1684D).  The PDF for the mount lists two separate motors, noting "double shaft" one one but not the other, and a weight difference of ~100g between them, but lists the same model number for both (which is the same model the README links to).  Is this right, or should the one designated D09 have a different model number noted?

The DEC motor doesn't have the double shaft. Only the RA motor does (for the brake).

> * The handle.  I haven't been able to find an equivalent to the Mentor 3270.0883 on Aliexpress, but maybe I'm not searching for the right thing.  Are you aware of an alternative?

The handle is here: https://fr.farnell.com/mentor/3270-0883/poignee-acier-88mm-noire/dp/4216398 or here https://www.newark.com/mentor/3270-0883/handle-steel-88mm-ctrs-black/dp/15J5728 if you are in the US. I tried hard to find an alternative but failed...

> * The Vixen/Losmandy dovetail clamp.  Is there a particular part you had in mind, or can I just pick one more or less at random from Aliexpress and expect the screw hole pattern to line up?

Not sure what Polvinc got. But I ended up getting something else with matching holes.

>   * It also looks like your design is missing three buttons compared to theirs: Shift, f, and F.  Are these implemented differently?  Are you using different code for the SHC?  Or am I just missing them?

I haven't looked very deeply at SHC at this point. But according to what I have seen, you will loose some functions related to using f and F buttons with this SHC. If you want to use an SHC with full functionality, you probably need to use another
SHC PCB while changing the ST4 connector to the 3.5mm audio jack connector. On the other hand, I plan to make another alternative to the HEMY board to use ST4 instead of 3.5mm jack.

Other possible errors in the BOM:
1. Two M5x14 hex bolts are missing in the base BOM, which are used to fix the Setting Alt to the Rotation Alt.
2. The RA belt should be 180mm rather than 200mm in the PDF BOM.
3. I found that using the 150mm belt on DEC is a bit tight and the motor doesn't fit without sanding the external shaft bearing retaining plate. I ordered an 154mm belt. Will see if it works better.

danb35, 2025-02-01:
> here https://www.newark.com/mentor/3270-0883/handle-steel-88mm-ctrs-black/dp/15J5728 if you are in the US

I'd hoped to not spend $10 in shipping for a $7 part, but I guess it can't be helped.  I guess the thing to do is to add more to the order, to spread out the cost, right?  Though it looks like their lead time is crazy.  I guess the handle isn't that critical a part, so I can add it after the fact if I need to.

> The DEC motor doesn't have the double shaft.

Are there any other particular characteristics I need to look for?  Or just NEMA 17, single shaft, 0.9°/step?

chunhaow, 2025-02-02:
Well, You will have to get the required rocker switch for the PCB from Newark/Farnell: https://www.newark.com/multicomp/4us1r102m7rn/switch-rocker-spdt-20v-black/dp/95M2277

So it makes sense to get the handle from them as well... I tried to find other sources for the switch, but couldn't find any.

Regarding the DEC motor, no other characteristics, just NEMA 17 single shaft, 0.9 deg/step should be fine. Also pay attention to the motor length. The BOM specified 47 or 48mm. I think slightly shorter motors would also work: the DEC motor doesn't need as much torque as the RA one.

polvinc, 2025-02-02:
Thank you chunhaow for your thoughtful replies, and for being more responsive than me!

Here are the ones I had in mind for the Vixen/Losmandy dovetail clamp. Now you need to look at the manufacturing drawing to make sure that the hole pattern matches the clamp you want. Another solution is to design another Harmonic/Vixen plug based on the existing one to fit the clamp you want:
[That one](https://fr.aliexpress.com/item/1005006483865820.html)
[This one](https://fr.aliexpress.com/item/1005005872254638.html)
Or the QR011 from Neewer.

For the DEC engine, you don't need a double shaft. I had this in stock, so I used it! Any Nema 17 with 0.9°/step will do. I've also designed the motor support to accommodate a Nema 14, but I haven't tested it.

polvinc, 2025-02-02:
> If the BOM in the PDFs is definitive, I could submit a PR to update the docs (probably in its own file rather than in the README itself). Would that be helpful?

Given that I haven't been able to be very reactive and free up time on this project in recent weeks, I'm actually looking for some help to make the readme more up to date and adjusted (from memory there are still a few errors in the BOM table in the readme). I'd also like, one day... to have some sort of assembly guide, like I did for DHEM.

danb35, 2025-02-02:
> I'm actually looking for some help to make the readme more up to date and adjusted

I'm not sure how much help I'll be on the rest of the README, but I'll try to have the BOM ready today.  Assembly guide would be nice, but I think can be figured out from the drawings (though I may yet eat those words, as I haven't tried it yet).  I'd think the bigger question would be for the firmware--there's lots of reference to TeenAstro, but it looks like their "flasher for dummies" only works with their boards and two stepper drivers, neither of which is the 2660.  So some notes on how to flash whatever needs to be flashed to wherever would be helpful.

danb35, 2025-02-02:
#13 submitted.

polvinc, 2025-02-02:
Thanks for this work. I reviewed and merged !

Closed 2025-02-15.

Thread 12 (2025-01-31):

Material for 3D-printed parts

danb35, 2025-01-31:
The parts list specifies SLS-printed Nylon for the 3D-printed parts.  Is this material necessary, or could FDM-printed PLA (or perhaps ABS or some other material) be used?  It doesn't appear that there are any real mechanical requirements for these parts, other than dimensional accuracy.

chunhaow, 2025-02-01:
I don't think it matters too much. I printed them in ABS without any problem. I think using PLA or PETG is also fine. Make sure you experiment with hole enlargement for the harmonic skirts, otherwise, vixen/harmonic plugs won't fit. ABS shrinks more and I used 0.35mm enlargement. For PLA or PETG maybe smaller values are sufficient.

polvinc, 2025-02-02:
> The parts list specifies SLS-printed Nylon for the 3D-printed parts. Is this material necessary, or could FDM-printed PLA (or perhaps ABS or some other material) be used? It doesn't appear that there are any real mechanical requirements for these parts, other than dimensional accuracy.

As chunhaow says, it doesn't really matter from a mechanical point of view. There's very little transverse stress on the skirt. I made it in SLS because it was cheap and much more efficient and pretty. But I printed it myself in ABS for the first versions.

Closed 2025-02-15.

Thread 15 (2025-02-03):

U1 doesn't fit main board

danb35, 2025-02-03:
I ordered a set of PCBs from JLCPCB.com using the Gerbers, BOM, and CPL files in this repo for v1.1.  This morning, I had an email from them saying that U1 (the m.2 connector) doesn't fit the PCB as designed--its locating pins don't match the holes in the board:
```
About the U1, the indicated pin is larger than the hole, it can't match, how about we cut the pin off? There is extra cost.
```

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

Here's the mounting footprint from the datasheet:

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

Link to the part:
https://www.lcsc.com/product-detail/Hard-Disk-Connector-SAS-SATA-M-2_FOXCONN-AS0BC21-S48BE-7H_C2761457.html

I'm not too concerned about the nominal extra cost, by itself.  And presumably they're still able to align the connector properly.  But it seems like a bug in the design.

chunhaow, 2025-02-03:
I think this is a bug. The holes on the PCB are too small to fit the m.2 adapter. See my post here: https://github.com/polvinc/HEMY/issues/8#issuecomment-2566800761

You need to edit the source file it using easyeda.

polvinc, 2025-02-03:
Outch, good find. We had this problem with the first batch of cards, and the drawing defect should have been corrected in the online version. Sorry for the sloppiness.
You have to use the PCBs from the online version: [https://oshwlab.com/lordzurp/teenastro-redux](https://oshwlab.com/lordzurp/teenastro-redux) and edit the footprint to put the correct diameters on the M.2 connector. I'm going to put a readme to that effect in the PCB folder, while [lordzurp](https://oshwlab.com/lordzurp/works) fixes the problem online.

polvinc, 2025-02-03:
@danb35 Which gerber did you take? The one on github, or the one on oshwlab?

danb35, 2025-02-03:
> Which gerber did you take? The one on github, or the one on oshwlab?

I used the v1.1 gerber from this repo.  Are those not usable?

polvinc, 2025-02-03:
> > Which gerber did you take? The one on github, or the one on oshwlab?
>
> I used the v1.1 gerber from this repo. Are those not usable?

If it's still possible for you, I recommend using the pcb on [Oshwlab](https://oshwlab.com/lordzurp/teenastro-redux). The error on the M.2 connector is still there, but there has mainly been a correction on the positioning of the GPS module, and on the brake driver. If you use the PCB from the github (my bad, I haven't modified it), there will be a little soldering to do on the brake driver, and a washer to add to the main board.
I can guide you if necessary.

danb35, 2025-02-03:
I'll see if JLC can still cancel the order.

I'm not sure I'm comfortable enough with EasyEDA to make this change.  I think I've correctly edited the footprint for that connector, but I'm not sure how I'd go about applying that to the existing board layout.

polvinc, 2025-02-03:
With JLCPCB, you can also encourage them to apply the necessary corrections so that the M.2 footprint is correct.

Regarding the main PCB, on the gerber on github, be warned that you'll need to add an M3 washer between the pcb and the teensy micromod. One of the teensy's SOT23s is touching the GPS module, so it needs to be spaced out a bit (problem corrected on oshwlab). On the brake driver v1.0, the one on the github, there's simply an omission of a 4.7k resistor upstream of the activation transistor (problem corrected on oshwlab). If you build this version, you'll have to cut a trace and solder a 4.7k resistor to correct the problem. I can guide you if necessary.

danb35, 2025-02-05:
JLC canceled the main board but not the brake board, so I will need to mod those when they arrive.  I was able to modify the footprint on the main board, so that one should be fine.  And Sparkfun says they shipped the Teensy yesterday.

Now to get the CNC'd parts ordered.  Would you happen to know of a more economical source than JLC for shipment to .us?

danb35, 2025-02-10:
Raised https://github.com/zUrp-Astronomics/Unicorn/issues/1 on the upstream repo.

Closed 2025-02-15.

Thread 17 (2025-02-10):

Enable discussions on this repo

danb35, 2025-02-10:
There seem to be a number of subjects that would be related to this project, but don't really qualify as issues (two that come to mind are "I have some spare boards" and "what's a good tripod to use with this mount?").  It seems that the GitHub discussions feature would be appropriate--could that be enabled on this repo?

polvinc, 2025-02-15:
Great idea, done!

Closed 2025-02-15.

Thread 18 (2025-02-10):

Add artwork for left plate

danb35, 2025-02-10:
It'd be helpful to have some artwork to laser-engrave (or perhaps silkscreen) on the left plate.  Functionally, it'd be helpful to mark the ports--something like PWR, 12-24V DC IN, SHC, USB-C.  Maybe even mark the power input as center-positive, though that's pretty much a standard any more.

Beyond that, that plate's a big open space where you could put some kind of logo for the mount.  Maybe even a URL or a QR Code for the repo.  If there's nothing "official," I'll probably do something along the lines of Cuiv's Order of Lazy Geeks, but something identifying the mount seems like a good idea.

polvinc, 2025-02-15:
Clearly, it's a good idea. For the time being, I've only made some HEMYs for testing, so I haven't applied myself too much to laser engraving. But apparently JLCCNC offers this service at a very low price. All you have to do is provide a DWG drawing. I'll think about it for my next mechanical order!

Closed 2025-04-08.

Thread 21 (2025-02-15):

What is the part for P1 on the brake driver board?

danb35, 2025-02-15:
I'm trying to figure out what part I need to use for P1 on the brake driver board.  It mates with a 2x2 2.54mm male pin header on the main PCB, so I could use a female pin header, but it looks like that would leave the driver board sitting too high above the main PCB to be able to secure it in place using the same screw that holds in the Teensy.  There's a note on the PCB layout from EasyEDA saying `Order this part in your JLC inventory: WR-PHD SMT 62100421821`.  I'm not able to find any such part from LCSC or JLC.  It'd be nice, of course, if the PCBA could handle it, but it doesn't look like it'd be too hard to hand-solder if needed.  Any idea what this part should be, and where I can get it?

polvinc, 2025-02-15:
You have two options:
- Either you buy this part through your JLC account, choosing a supplier alernative to LCSC, and they automatically weld it during the SMT process. That's what I did by buying from Farnell via my JLC account.
- Or you can buy the part yourself and solder it yourself.

danb35, 2025-02-15:
My question was more what the part was, but the pointer to Farnell has me a lot closer.  But still not quite there; the closest I see is this: https://uk.farnell.com/wurth-elektronik/62130421821/conn-rcpt-4pos-2row-2mm/dp/3819101 -- one digit different in the part number.  But the datasheets at Würth (https://www.we-online.com/en/components/products/PHD_2_0_SMT_DUAL_SOCKET_HEADER_LOW_PROFILE_6210XX21821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) seem to indicate the only difference is that the 6213 part (which is what Farnell lists) comes on tape and has a plastic cap (which would presumably be needed for pick-and-place assembly), while the 6210 part comes in a tube and has no cap.

Is the 6213 part as equivalent as it appears, or am I missing something?

chunhaow, 2025-02-15:
You can get it from digikey or mouser, https://www.digikey.com/en/products/detail/samtec-inc/CLT-102-02-F-D-TR/6692113

danb35, 2025-02-15:
> digikey or mouser

Thanks.  I asked Würth for a few samples and will see what they say; otherwise Digikey will save a few bucks compared to Newark.

Closed 2025-02-24.

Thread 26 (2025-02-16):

LED and TIME_LOCATION_SOURCE in Config.h

chunhaow, 2025-02-16:
Since LED2 is active high connecting to the MCU, The following line should be added. Otherwise, it won't stay on if there is no error.

`#define STATUS_LED_ON_STATE           HIGH`

Also, the following should be used to choose GPS as the main time/location source, and use Teensy as a backup before GPS is connected to satellites:
```
#define TIME_LOCATION_SOURCE          GPS //    OFF, DS3231 (I2C,) SD3031 (I2C,) TEENSY (T3.2 etc,) GPS, or NTP source.       Option
                                          //         Provides Date/Time, and if available, PPS & Lat/Long also.
#define TIME_LOCATION_SOURCE_FALLBACK TEENSY
```

polvinc, 2025-02-19:
Good point, I'm changing the config.h

Closed 2025-02-24.

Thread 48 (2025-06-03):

Screw adjustments in BOM

polar-beard, 2025-06-03:
Since you suggested we could try to help tune the BOM with screw lengths, I've been looking in the STEP model. I didn't manage to find any optimizations yet, as you already have a very well thought out design! But I did get a couple of questions comparing the CAD to the BOM. Maybe you can share your thoughts on them?

1. According to the CAD there seems to be a very slight collision with the M3 screws on Lateral A and Lateral B
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

2. I found two places where the CAD doesn't have screws. I'm not sure if that also means they are missing from the BOM, do you know the status of these?
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

3. Screws for polar viewfinder in CAD are 2 pcs. 8mm length and 2 pcs. 10mm length. Have the 8mm been removed from the BOM since to simplify it?
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

polar-beard, 2025-06-10:
Thanks for making this big effort for an open source project! We will be running a group buy of parts in the next days, if you know somebody who might want to participate then throw them our way. I think most people who participated in the group-buy thread have seen it now.

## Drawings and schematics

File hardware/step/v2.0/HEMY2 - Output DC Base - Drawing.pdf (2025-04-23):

Ø64
0,5 X 45,0°

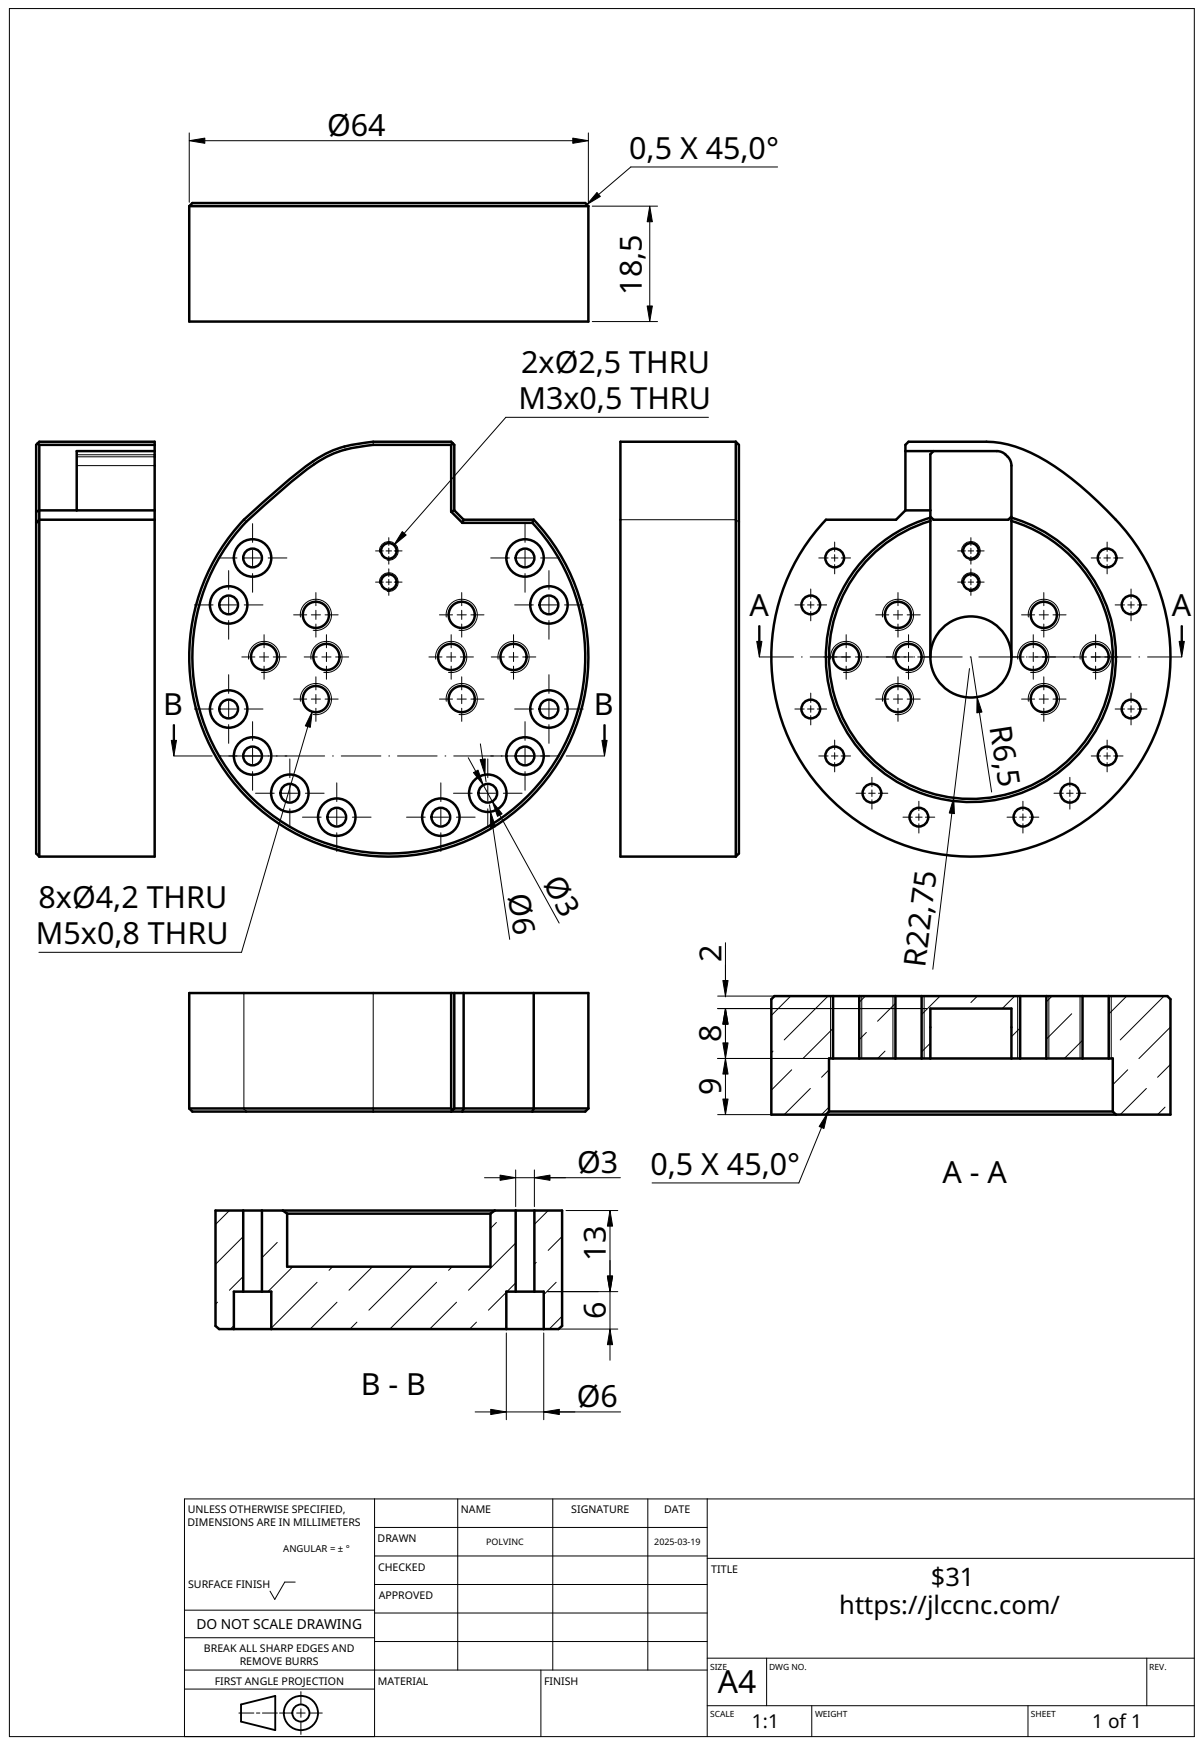
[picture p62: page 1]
MATERIAL; FINISH; 8xØ4,2 THRU M5x0,8 THRU; 2xØ2,5 THRU M3x0,5 THRU

UNLESS OTHERWISE SPECIFIED, DIMENSIONS ARE IN MILLIMETERS ANGULAR = ± ° SURFACE FINISH | | NAME | SIGNATURE | DATE

DRAWN | POLVINC | | 2025-03-19

CHECKED | | | | TITLE $31 https://jlccnc.com/

APPROVED

DO NOT SCALE DRAWING

BREAK ALL SHARP EDGES AND

REMOVE BURRS
FIRST ANGLE PROJECTION

SIZE A4 | DWG NO. | REV.

SCALE 1:1 | WEIGHT | SHEET 1 of 1

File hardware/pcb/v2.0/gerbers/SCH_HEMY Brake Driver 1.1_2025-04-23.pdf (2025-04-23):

## Power saving PWM brake controller Alim 12-25V boost out 24V

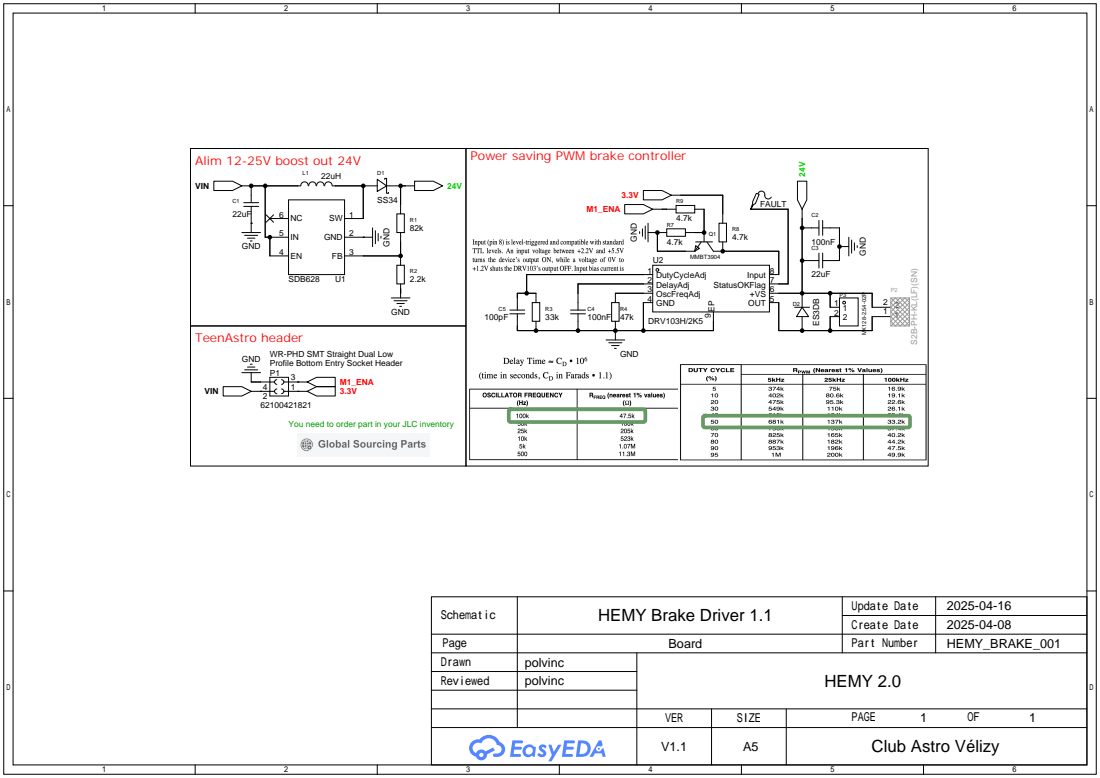
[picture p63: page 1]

WR-PHD SMT Straight Dual Low
GND
Profile Bottom Entry Socket Header
You need to order part in your JLC inventory

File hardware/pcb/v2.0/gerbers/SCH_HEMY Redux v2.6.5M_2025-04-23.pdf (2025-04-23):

# Teensy

+3.3V

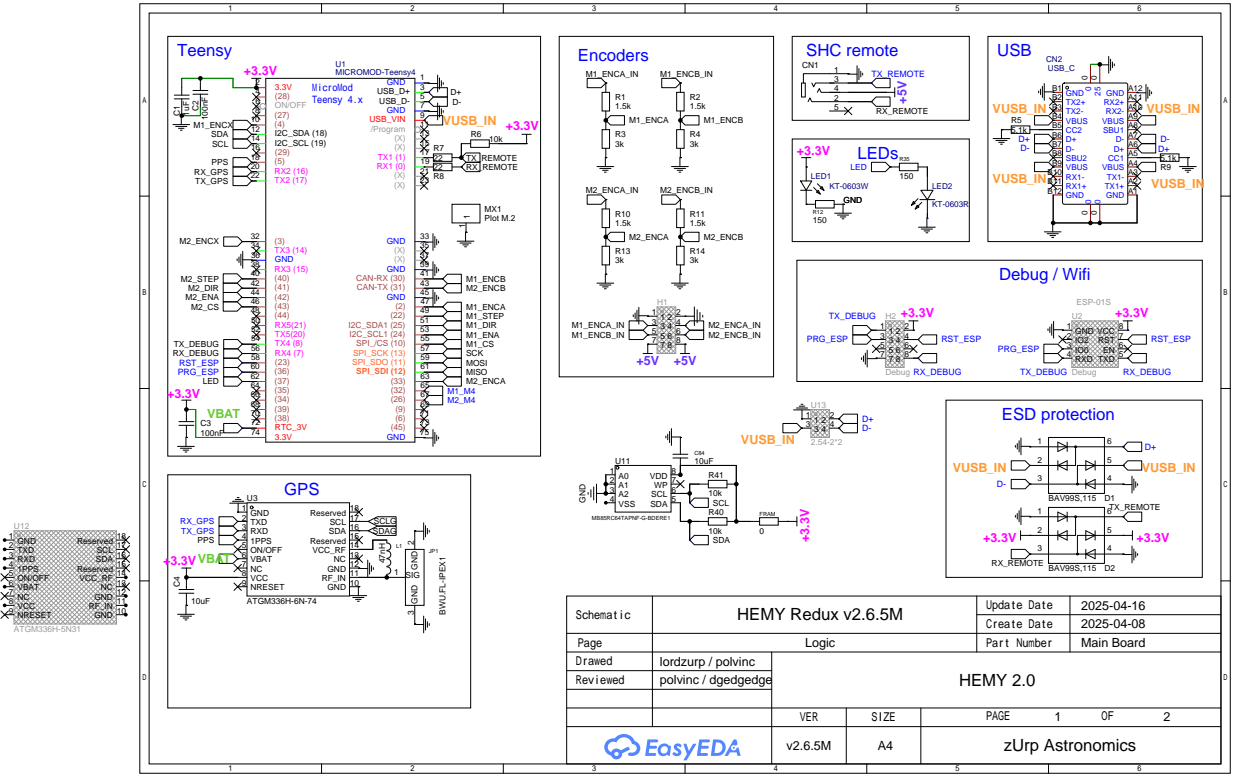
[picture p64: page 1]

# Motor 1 (RA/ AZ)

# Power reverse protection (25V max)

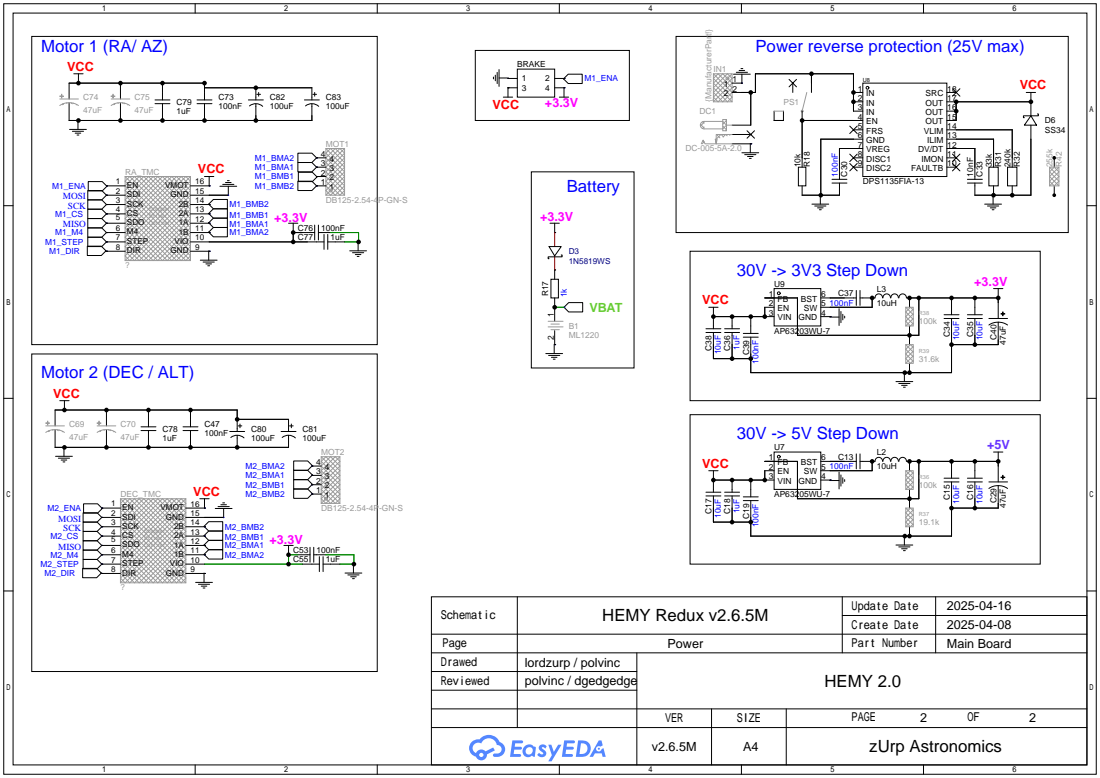
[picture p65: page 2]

FAULTB 10 IMON 11 DV/DT 12 ILIM 13 VLIM 14 OUT 15 OUT 16 OUT 17 SRC 18

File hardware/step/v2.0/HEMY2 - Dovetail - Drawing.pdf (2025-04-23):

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

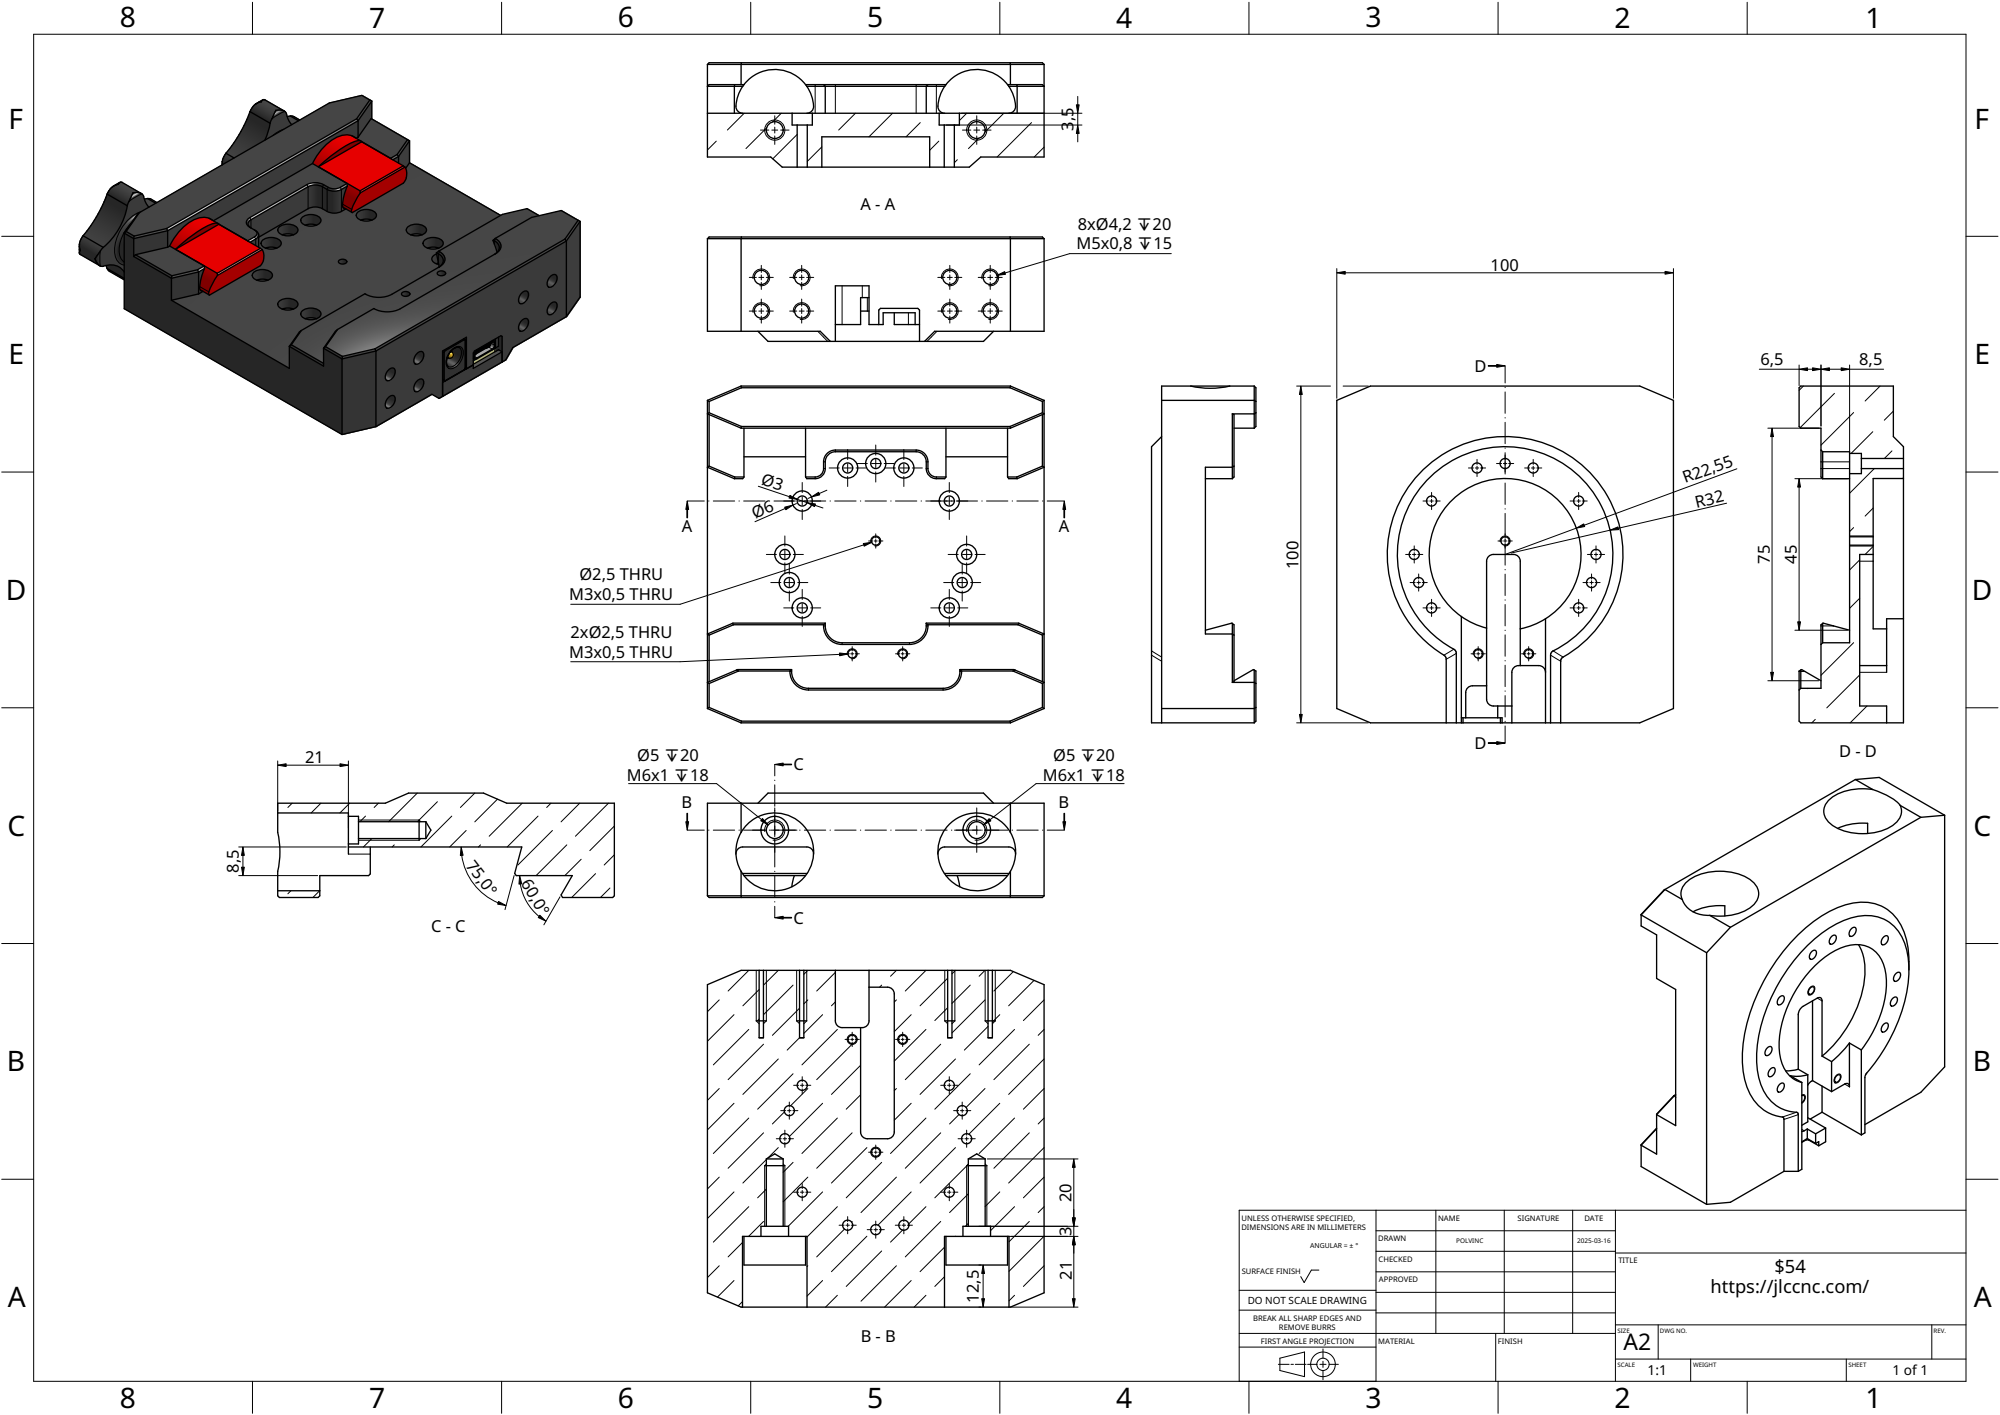
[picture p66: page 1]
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

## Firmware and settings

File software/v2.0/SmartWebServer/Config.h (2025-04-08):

/* ---------------------------------------------------------------------------------------------------------------------------------
 *                                       Configuration for the OnStep SmartWebServer
 *
 *           For more information on setting up the Smart Web Server see https://onstep.groups.io/g/main/wiki/7119
 *                               and join the OnStep Groups.io at https://groups.io/g/onstep
 * 
 *         *** Read the compiler warnings and errors, they are there to help guard against invalid configurations ***
 *
 *      For Wifi successful startup an AP will appear with an default SSID of "ONSTEP" and default password of "password".
 *      After connecting the web-site is at "192.168.0.1" and the cmd channels are at "192.168.0.1:9996 to 9999". If locked
 *      out selecting "Erase Flash: All Flash Contents" from the Arduino IDE Tools menu before uploading/flashing again can
 *      help restore access to the ESP8266 or ESP32; or see Extended.config.h to wipe NV.
 *
 *   For Ethernet DHCP and mDNS are active by default so OnStep can usually be reached at "onstepsws.local" or by checking your
 *   LAN's Router or Access Point to see what IP Address was assigned.
 *   You can also manually configure the SWS network settings and static IP in Extended.config.h so they match your LAN instead.
 *
 * ---------------------------------------------------------------------------------------------------------------------------------
 * ADJUST THE FOLLOWING TO CONFIGURE YOUR CONTROLLER FEATURES ----------------------------------------------------------------------
 *
 * <-Req'd = always must set, <-Often = usually must set, Option = optional, Adjust = adjust as req'd, Infreq = infrequently changed
 */
//      Parameter Name              Value   Default  Notes                                                                      Hint

// =================================================================================================================================
// CONTROLLER ======================================================================================================================

#define HOST_NAME            "HEMY-SWS" // p-SWS", This devices name up to 16 chars (collapses to mDNS name "onstepsws".)   Adjust

// OPERATIONAL MODE ----------------------------------------------------------------------------------------------------------------
#define OPERATIONAL_MODE             WIFI //   WIFI, Or use ETHERNET_W5100 or ETHERNET_W5500                                 <-Req'd

// SERIAL PORTS --------------------------------------------------------------------------------------------------------------------
#define SERIAL_BAUD_DEFAULT          9600 //   9600, Common baud rates for this parameter are 9600,19200,57600,115200,etc.    Infreq
                                          //         The OnStep serial port this is wired to must use the same rate above.
#define SERIAL_BAUD                115200 // 115200, Or use 19200,57600,115200,230400,460800 (not all devices support > 115200)
                                          //         (OnStep and here.)  Automatically uses 19200 if talking to a Mega2560 OnStep.
#define SERIAL_SWAP                  AUTO //   AUTO, Automatic check both, ON for swapped port or OFF for default port only.  Infreq
                                          //         this option is ignored in ETHERNET modes

// BLE GAMEPAD SETTINGS (ESP32 ONLY) ------------------------------------------------ see https://onstep.groups.io/g/main/wiki/26762
#define BLE_GAMEPAD                   OFF //    OFF, ON to allow BLE gamepad connection for ESP32 only.                       Option
#define BLE_GP_ADDR   "ff:ff:de:09:f5:cf" // f5:cf", GamePad MAC address #1                                                   Adjust
                                          //         GamePad device address must match exactly else it will not connect!
                                          //         Replace address with yours, in lower case, with colons as shown.
#define BLE_GP_ADDR1  "ff:ff:ff:ff:ff:ff" // ff:ff", GamePad MAC address #2                                                   Adjust
                                          //         Two GamePads are allowed, operating in a "handoff" mode, one at time.

// STATUS LED ----------------------------------------------------------------------------------------------------------------------
#define LED_STATUS                     ON //     ON, Enable LED flashes while connecting then steady once connected.          Infreq
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

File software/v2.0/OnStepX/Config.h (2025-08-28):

/* ---------------------------------------------------------------------------------------------------------------------------------
 * Configuration for OnStepX
 *
 *          For more information on setting OnStep up see http://www.stellarjourney.com/index.php?r=site/equipment_onstep 
 *                      and join the OnStep Groups.io at https://groups.io/g/onstep
 * 
 *           *** Read the compiler warnings and errors, they are there to help guard against invalid configurations ***
 *
 * ---------------------------------------------------------------------------------------------------------------------------------
 * ADJUST THE FOLLOWING TO CONFIGURE YOUR CONTROLLER FEATURES ----------------------------------------------------------------------
 * <-Req'd = always must set, <-Often = usually must set, Option = optional, Adjust = adjust as req'd, Infreq = infrequently changed
*/
//      Parameter Name              Value   Default  Notes                                                                      Hint

// =================================================================================================================================
// HEMY Tests
/*
:hF#:Te#:Td#:Sz180:00:00#:Sas00:00:00#:MA#
:hF#:Te#:Td#:Sr00:00:00#:Sds00:00:00#:CM#:hQ#:hP#
:hQ#:hP#    PARK here
:hP#        PARK
:hR#        PARK release
:R9#        SPEED x9
:Q#         STOP
:ERESET#    RESET

:SC12/13/24#:SL22:30:00#:SGs01#  // SET date + time + UTC offset
:hR#  // Release Park
:hF#:Te#:Td#     // Reset Home
:Sr11:05:16#:Sds61:36:41#:MS#     // Target Dubhe + Goto
:Sr09:57:37#:Sds68:56:34#:MS#     // Target Dubhe + Goto
:hC#     //Move to home

*/
// HEMY Config
#define DRIVER_TMC_STEPPER
#define DRIVER_TMC_STEPPER_HW_SPI
#define TMC2660_RSENSE 0.075F

#define SERIAL_A                Serial           // USB
#define SERIAL_B                Serial4          // ESP-01s
#define SERIAL_C                Serial1          // Remote

#define SERIAL_GPS              Serial2          // Hardware GPS
#define SERIAL_GPS_BAUD         115200

#define AUX0_PIN                37               // Status LED
#define STATUS_LED_PIN          AUX0_PIN         // Default LED Cathode (-)
#define MOUNT_LED_PIN           AUX0_PIN         // Default LED Cathode (-)
#define STATUS_LED_ON_STATE     HIGH

// The PPS pin is a 3.3V logic input, OnStep measures time between rising edges and adjusts the internal sidereal clock frequency
#define PPS_SENSE_PIN           5                // PPS time source, GPS for example
#define TIME_LOCATION_SOURCE_FALLBACK        TEENSY

// Axis1 RA/Azm step/dir driver
#define AXIS1_ENABLE_PIN        42//24
#define AXIS1_M0_PIN            11               // SPI MOSI
#define AXIS1_M1_PIN            13               // SPI SCK
#define AXIS1_M2_PIN            43//10               // SPI CS (UART TX)
#define AXIS1_M3_PIN            12               // SPI MISO (UART RX)
#define AXIS1_STEP_PIN          40//22
#define AXIS1_DIR_PIN           41//25
#define AXIS1_FAULT_PIN         AXIS2_M3_PIN     // SPI MISO
#define AXIS1_DRIVER_INTPOL     ON               // use interpolation if available

// Axis2 Dec/Alt step/dir driver
#define AXIS2_ENABLE_PIN        24//42
#define AXIS2_M0_PIN            11               // SPI MOSI
#define AXIS2_M1_PIN            13               // SPI SCK
#define AXIS2_M2_PIN            10//43               // SPI CS (UART TX)
#define AXIS2_M3_PIN            12               // SPI MISO (UART RX)
#define AXIS2_STEP_PIN          22//40
#define AXIS2_DIR_PIN           25//41
#define AXIS2_FAULT_PIN         AXIS1_M3_PIN
#define AXIS2_DRIVER_INTPOL     ON               // use interpolation if available

#define ADDON_GPIO0_PIN         36               // ESP8266 GPIO0
#define ADDON_RESET_PIN         23               // ESP8266 RST

// CONTROLLER ======================================================================================================================

// PINMAP ------------------------------------------------- see https://onstep.groups.io/g/main/wiki/Configuration_Controller#PINMAP
#define PINMAP                        OFF //    OFF, Choose from: MiniPCB, MiniPCB2, MaxPCB2, MaxESP3, CNC3, STM32Blue,      <-Req'd
                                          //         MaxSTM3, FYSETC_S6_2, etc.  Other boards and more info. in ~/src/Constants.h
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

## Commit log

2024-07-03 add STEP files
    [01 - Main plate - Main plate.step, 02 - R plate - R plate.step, 03 - L plate - L plate.step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]
2024-12-03 move step upgrade
    [01 - Main plate - Main plate.step, 02 - R plate - R plate.step, 03 - L plate - L plate.step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]
2024-12-04 add gerbers
    [BOM_HEMY Brake Driver 1.0_HEMY Brake Driver 1.0_2024-12-04.xlsx, BOM_SHC Redux - v1.5.3_SHC Redux - v1.5.2_2024-12-04.xlsx, BOM_TeenAstro Redux v2.6.4B_Redux v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]
2025-02-02 Update BOM
    Break out BOM into separate file and update to match PDF drawings
2025-02-02 Update BOM.md
    Specify 6mm width for all GT2 pulleys, and correct bore for larger pulleys to 8mm.
2025-02-03 M.2 footprint fault, and transistor resistance fault
    [BOM_HEMY Brake Driver 1.0_HEMY Brake Driver 1.0_2024-12-04.xlsx, BOM_SHC Redux - v1.5.3_SHC Redux - v1.5.2_2024-12-04.xlsx, BOM_TeenAstro Redux v2.6.4B_Redux v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]
2025-02-03 Update BOM.md
    Update stepper qty and part number, add link to OSHWLab, explain standard hardware.
2025-03-20 added v2 STEP and PCB project files
    Warning, this is currently the as-built version, but not tested.
    [HEMY2 - Bottom plate.step, HEMY2 - Brake support.step, HEMY2 - Dovetail Fix.step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]
2025-03-20 basic readme for STEP and PCB
2025-03-22 add gerber and BOM
    [BOM_AstrAlim_AstrAlim PCB_2025-03-09.xlsx, BOM_DC USB Dovetail_PCB5_2_2025-03-09.xlsx, BOM_HEMY Brake Driver 1.1_HEMY Brake Driver 1.1_2025-03-09.xlsx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]
2025-03-22 correction step dovetail
    [HEMY2 - Dovetail Fix.step, HEMY2 - Dovetail.step]
2025-04-20 first pictures in assembly.md
2025-04-20 Update HEMY2 - Pulley 70Ts CNC.step
    [HEMY2 - Pulley 70Ts CNC.step]
2025-04-20 Update HEMY2 - Brake support.step
    [HEMY2 - Brake support.step]
2025-04-21 Updates on step files minor corrections
    [HEMY2 - Lateral A.step, HEMY2 - Top plate without antennas.step, HEMY2 - Top plate.step]
2025-04-21 Update dovetail, minor corrections
    [HEMY2 - Dovetail Fix.step, HEMY2 - Dovetail.step]
2025-04-23 update repo architecture
    [01 - Main plate - Main plate.step, 02 - R plate - R plate.step, 03 - L plate - L plate.step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]
2025-04-23 update gerbers
    [3D_PCB5_1_2025-04-23.step, BOM_AstrAlim_AstrAlim PCB_2025-03-09.xlsx, BOM_DC USB Dovetail_PCB5_2_2025-03-09.xlsx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]
2025-04-23 Create HEMY2 - SWB-003-shaft coupling.step
    [HEMY2 - SWB-003-shaft coupling.step]
2025-05-02 Update Config.h
    AXIS REVERSE to OFF
    [Config.h]
2025-05-07 Update BOM.md
    ref for the wifi antenna
2025-05-14 Update BOM.md : Simplify pitch
2025-05-25 Update added notes + remove (uneeded nut grade) BOM.md
2025-05-28 Update Assembly instructions
2025-06-23 Upadte gerber, main board with components in stock
    [BOM_HEMY TeenAstro Redux v2.6.5M_HEMY Redux v2.6.5M_2025-04-23.xlsx, BOM_HEMY TeenAstro Redux v2.6.5M_HEMY Redux v2.6.5M_2025-06-23.xlsx, PickAndPlace_HEMY Red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]
2025-08-31 Update Assembly.md upades
2025-08-31 Update Assembly.md update2
